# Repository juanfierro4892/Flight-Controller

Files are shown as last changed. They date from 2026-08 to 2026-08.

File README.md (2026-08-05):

Flight Controller 

This is a custom flight controller designed for control rockets.
It uses an STM32F722 microcontroller, ICM-45686 IMU, BMP580 barometer, and has a microSD card for logging flight data. It supports 2S LiPo batteries with onboard charging and has PWM outputs for controlling servos.

The board was designed in KiCad and is fully open source.

PCB: 

3D image: 


Schematic: 


Assembly:

There is no assembly instructions because as it have a lot of components there come assembled from the manufacturer aka JLCPCB

Technical Specifications
Brain: STM32F722RET6 microcontroller.

IMU: ICM-45686 high-precision motion sensor.

Barometer: BMP580 altitude tracker.

Actuation: Multi-channel Servo output via PWM.

Data Logging: Onboard MicroSD card slot.

Power Management:

BQ25883: 2-cell LiPo battery charger via USB-C.

TPS63070: 5V Buck-Boost regulator for servos.

LMR51430: 3.3V Buck regulator for the MCU and sensors..

D2: RGB LED (Common Anode) — Visual status indicator for system boot, ready-to-fly state, and critical errors (IMU, battery, SD card, and power rails).

It is coded in C in visual studio code.

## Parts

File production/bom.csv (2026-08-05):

Designator | Footprint | Quantity | Value | LCSC Part #
C1, C28, C29, C30 | 0402 | 4 | 1uF
C10, C11, C13 | 0805 | 3 | 22uF
C12, C2, C9 | 0603 | 3 | 10uF
C14, C15, C19, C20, C21, C22, C23, C24, C25, C26, C27, C37 | 0201 | 12 | 100nF
C16 | 0603 | 1 | 2.2uF
C17, C18 | 0402 | 2 | 22uF
C3, C31, C5 | 0402 | 3 | 10uF
C32 | 0201 | 1 | 2.2uF
C33, C34 | 0201 | 2 | 20pF
C35, C36 | 0201 | 2 | 6.8pF
C4 | 0201 | 1 | 47nF
C6 | 0603 | 1 | 44uF
C7, C8 | 0805 | 2 | 10uF
CARD1 | TF-SMD_TF-01A | 1 | TF-01A | C91145
D1 | 0402 | 1 | LED
J1 | TerminalBlock_Xinya_XY308-2.54-2P_1x02_P2.54mm_Horizontal | 1 | Screw_Terminal_01x02
J2, J3 | PinHeader_1x03_P2.54mm_Vertical | 2 | Conn_01x03
L4 | L0603 | 1 | FCM1608KF-601T03 | C141723
L5 | L2520 | 1 | DFE252012F-1R0M=P2 | C435392
L6 | IND-SMD_L4.0-W4.0-A | 1 | XFL4020-152MEC | C3033018
L7 | IND-SMD_L3.0-W3.0 | 1 | YHNR3015-5R6M | C18236327
R1, R2 | 0201 | 2 | 5.1K
R10, R11, R12, R13, R16, R17, R18, R19, R20, R21, R22, R6, R7, R8, R9 | 0201 | 15 | 10K
R14 | 0402 | 1 | 100K
R15 | 0402 | 1 | 22.1K
R3 | 0201 | 1 | 383
R4 | 0201 | 1 | 5.23K
R5 | 0201 | 1 | 30.1K
SW1, SW2 | SW-SMD_L3.9-W3.0-P4.45 | 2 | TS-1088-AR02016 | C720477
U1 | VFQFPN-24_L4.0-W4.0-P0.50-BL-EP2.8 | 1 | BQ25883RGER | C544362
U2 | LGA-14_L3.0-W2.5-P0.50-TL | 1 | ICM-45686 | C22459454
U3 | LQFP-64_10x10mm_P0.5mm | 1 | STM32F722RETx
U4 | LGA-10_L2.0-W2.0-P0.50-TL_BMP580 | 1 | BMP580 | C22391138
U5 | VQFN-HR-15_L3.0-W2.5-P0.50-BL_TPS63070RNMR | 1 | TPS63070RNMR | C109322
U6 | SOT-23-6 | 1 | LMR51430
USB1 | USB-C-SMD_TYPE-C-16PIN-2MD-073 | 1 | TYPE-C 16PIN 2MD | C2765186
X1 | CRYSTAL-SMD_4P-L3.2-W2.5-BL | 1 | X322525MOB4SI | C9006
X2 | FC-135R_L3.2-W1.5 | 1 | Q13FC1350000400 | C32346

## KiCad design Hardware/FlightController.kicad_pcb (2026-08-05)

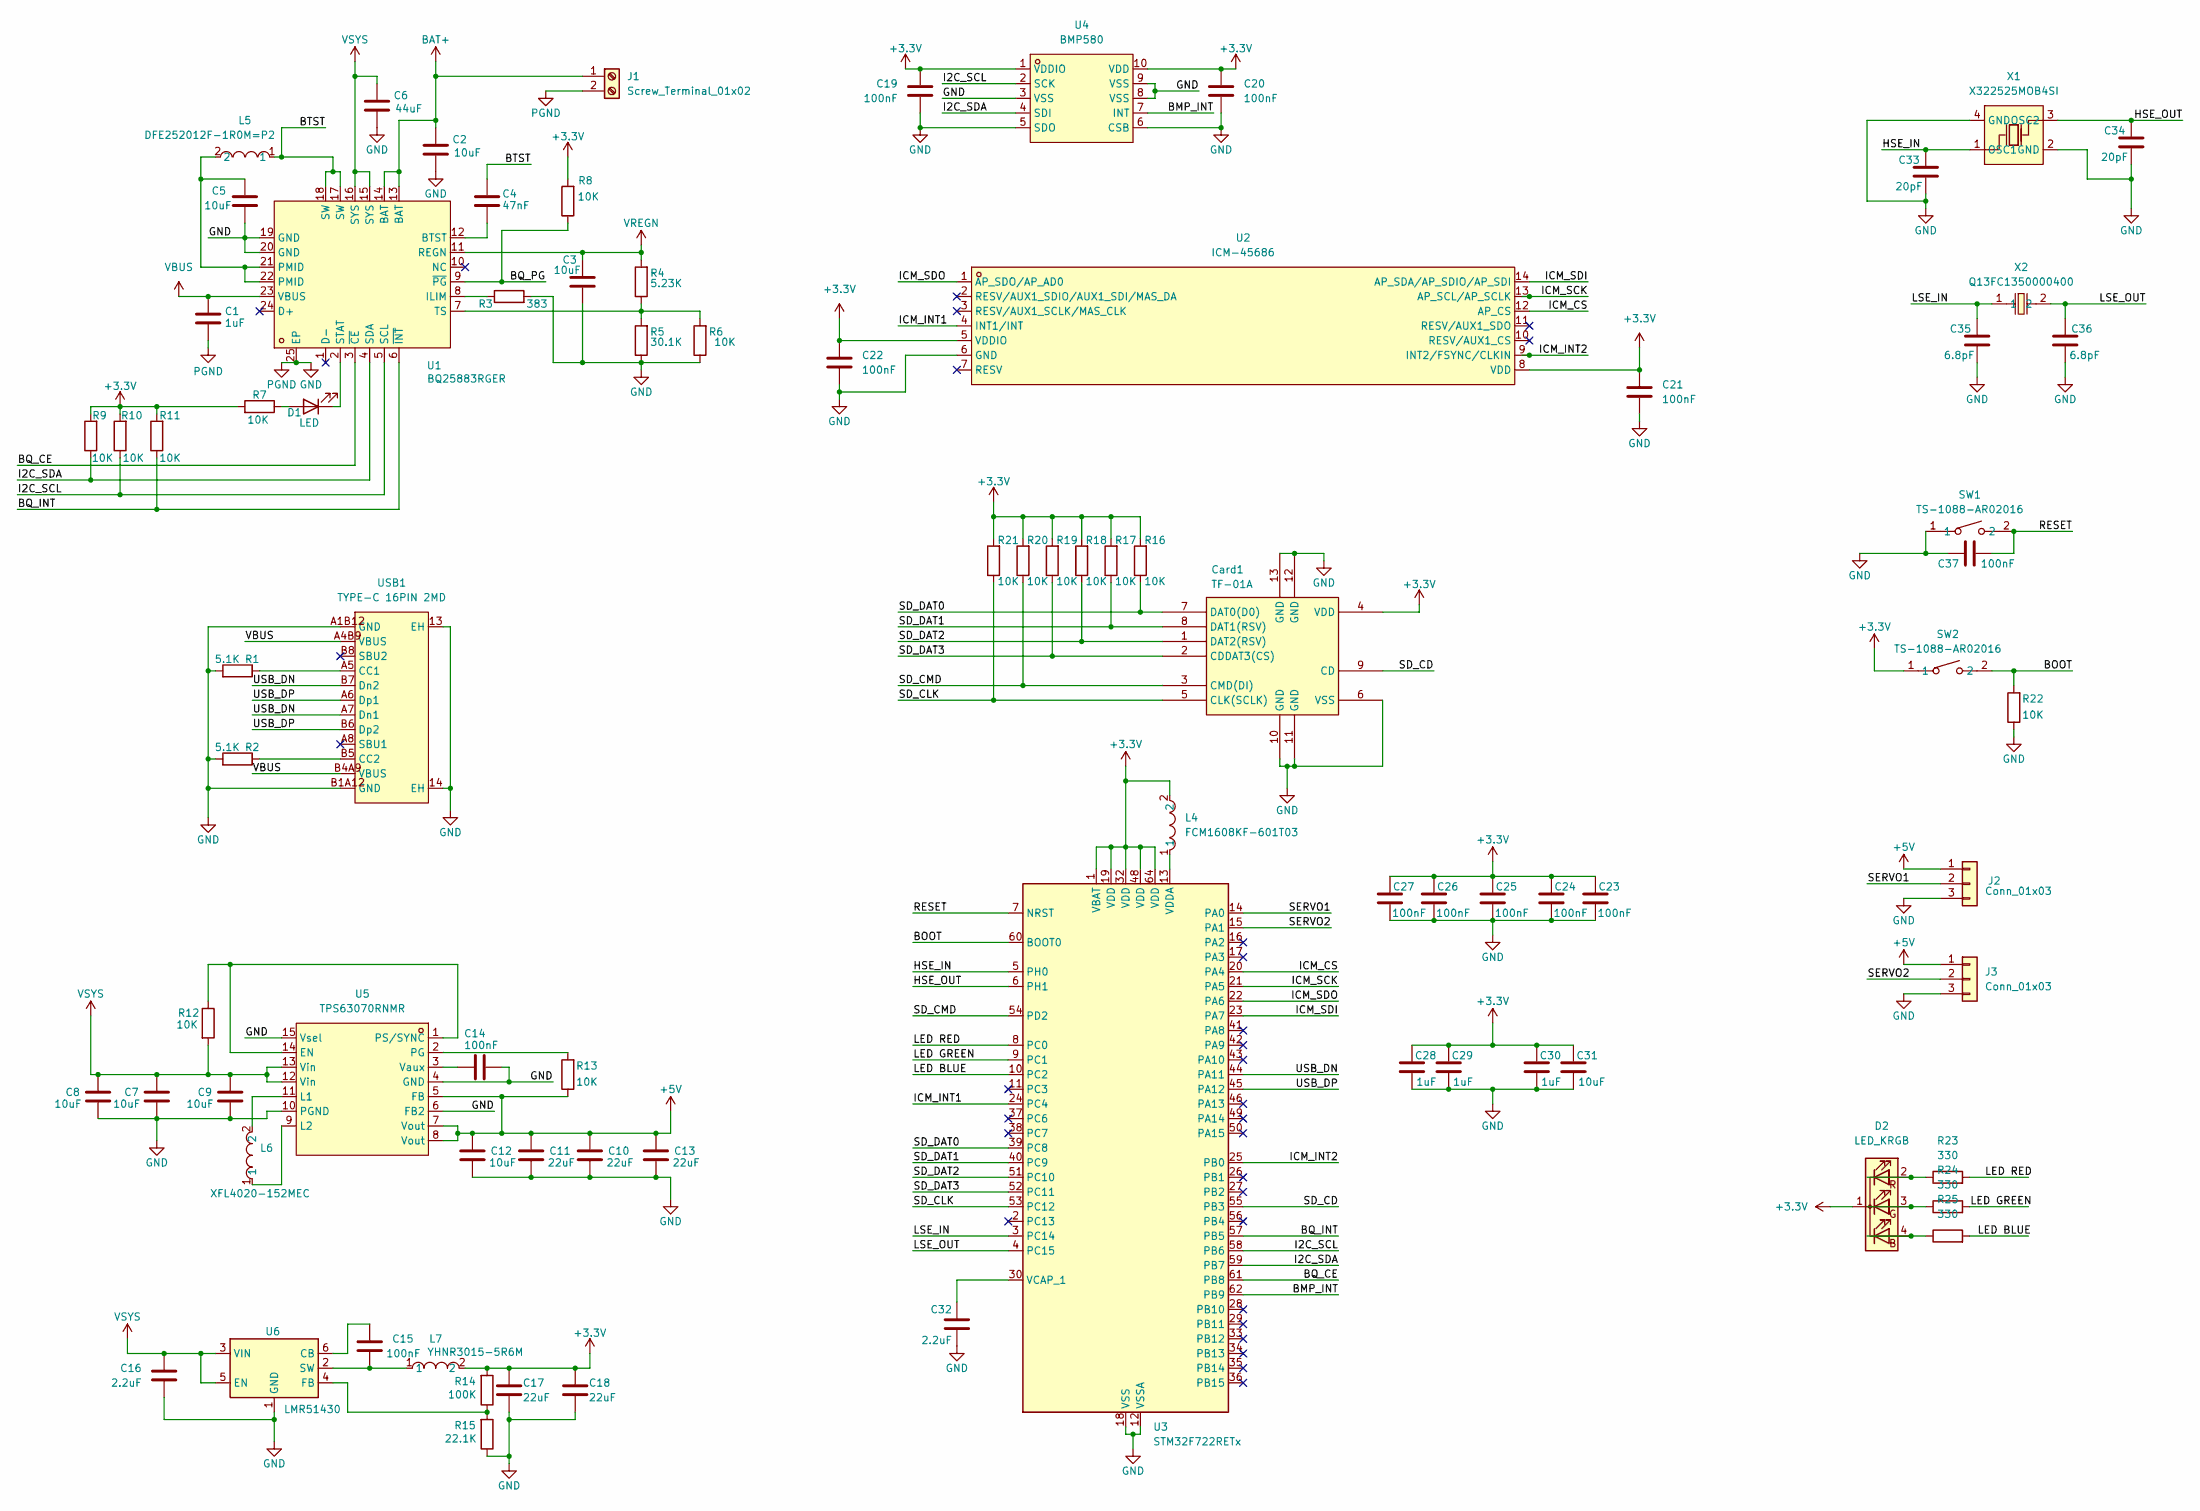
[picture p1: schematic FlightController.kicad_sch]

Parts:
C1, C28, C29, C30: 1uF; C_0402_1005Metric
C2, C9, C12: 10uF; C_0603_1608Metric
C3, C5, C31: 10uF; C_0402_1005Metric
C4: 47nF; C_0201_0603Metric
C6: 44uF; C_0603_1608Metric
C7, C8: 10uF; C_0805_2012Metric
C10, C11, C13: 22uF; C_0805_2012Metric
C14, C15, C19, C20, C21, C22, C23, C24, C25, C26, C27, C37: 100nF; C_0201_0603Metric
C16: 2.2uF; C_0603_1608Metric
C17, C18: 22uF; C_0402_1005Metric
C32: 2.2uF; C_0201_0603Metric
C33, C34: 20pF; C_0201_0603Metric
C35, C36: 6.8pF; C_0201_0603Metric
Card1: TF-01A; TF-SMD_TF-01A; LCSC Part C91145
D1: LED; LED_0402_1005Metric
D2: LED_KRGB; LED_Avago_PLCC4_3.2x2.8mm_CW
J1: Screw_Terminal_01x02; TerminalBlock_Xinya_XY308-2.54-2P_1x02_P2.54mm_Horizontal
J2, J3: Conn_01x03; PinHeader_1x03_P2.54mm_Vertical
L4: FCM1608KF-601T03; L0603; LCSC Part C141723
L5: DFE252012F-1R0M=P2; L2520; LCSC Part C435392
L6: XFL4020-152MEC; IND-SMD_L4.0-W4.0-A; LCSC Part C3033018
L7: YHNR3015-5R6M; IND-SMD_L3.0-W3.0; LCSC Part C18236327
R1, R2: 5.1K; R_0201_0603Metric
R3: 383; R_0201_0603Metric
R4: 5.23K; R_0201_0603Metric
R5: 30.1K; R_0201_0603Metric
R6, R7, R8, R9, R10, R11, R12, R13, R16, R17, R18, R19, R20, R21, R22: 10K; R_0201_0603Metric
R14: 100K; R_0402_1005Metric
R15: 22.1K; R_0402_1005Metric
R23, R24, R25: 330; R_0201_0603Metric
SW1, SW2: TS-1088-AR02016; SW-SMD_L3.9-W3.0-P4.45; LCSC Part C720477
U1: BQ25883RGER; VFQFPN-24_L4.0-W4.0-P0.50-BL-EP2.8; LCSC Part C544362
U2: ICM-45686; LGA-14_L3.0-W2.5-P0.50-TL; LCSC Part C22459454
U3: STM32F722RETx; LQFP-64_10x10mm_P0.5mm
U4: BMP580; LGA-10_L2.0-W2.0-P0.50-TL_BMP580; LCSC Part C22391138
U5: TPS63070RNMR; VQFN-HR-15_L3.0-W2.5-P0.50-BL_TPS63070RNMR; LCSC Part C109322
U6: LMR51430; SOT-23-6
USB1: TYPE-C 16PIN 2MD; USB-C-SMD_TYPE-C-16PIN-2MD-073; MPN TYPE-C 16PIN 2MD(073); LCSC Part C2765186
X1: X322525MOB4SI; CRYSTAL-SMD_4P-L3.2-W2.5-BL; LCSC Part C9006
X2: Q13FC1350000400; FC-135R_L3.2-W1.5; LCSC Part C32346

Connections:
+3.3V: C17.1, C18.1, C19.1, C20.1, C21.1, C22.1, C23.1, C24.1, C25.1, C26.1, C27.1, C28.1, C29.1, C30.1, C31.1, Card1.4 (VDD), D2.1 (K), L4.2, L7.2, R7.2, R8.2, R9.2, R10.2, R11.2, R14.2, R16.2, R17.2, R18.2, R19.2, R20.2, R21.2, SW2.1, U2.5 (VDDIO), U2.8 (VDD), U3.1 (VBAT), U3.19 (VDD), U3.32 (VDD), U3.48 (VDD), U3.64 (VDD), U4.1 (VDDIO), U4.10 (VDD)
+5V: C10.1, C11.1, C12.1, C13.1, J2.1, J3.1, R13.1, U5.5 (FB), U5.7 (Vout), U5.8 (Vout)
/BMP_INT: U3.62 (PB9), U4.7 (INT)
/BOOT: R22.2, SW2.2, U3.60 (BOOT0)
/BQ_CE: U1.3 (~CE), U3.61 (PB8)
/BQ_INT: R11.1, U1.6 (~INT), U3.57 (PB5)
/BQ_PG: R8.1, U1.9 (~PG)
/BTST: C4.1, L5.1, U1.17 (SW), U1.18 (SW)
/HSE_IN: C33.1, U3.5 (PH0), X1.1 (OSC1)
/HSE_OUT: C34.1, U3.6 (PH1), X1.3 (OSC2)
/I2C_SCL: R10.1, U1.5 (SCL), U3.58 (PB6), U4.2 (SCK)
/I2C_SDA: R9.1, U1.4 (SDA), U3.59 (PB7), U4.4 (SDI)
/ICM_CS: U2.12 (AP_CS), U3.20 (PA4)
/ICM_INT1: U2.4 (INT1/INT), U3.24 (PC4)
/ICM_INT2: U2.9 (INT2/FSYNC/CLKIN), U3.25 (PB0)
/ICM_SCK: U2.13 (AP_SCL/AP_SCLK), U3.21 (PA5)
/ICM_SDI: U2.14 (AP_SDA/AP_SDIO/AP_SDI), U3.23 (PA7)
/ICM_SDO: U2.1 (AP_SDO/AP_AD0), U3.22 (PA6)
/LED BLUE: R25.2, U3.10 (PC2)
/LED GREEN: R24.2, U3.9 (PC1)
/LED RED: R23.2, U3.8 (PC0)
/LSE_IN: C35.1, U3.3 (PC14), X2.1
/LSE_OUT: C36.1, U3.4 (PC15), X2.2
/RESET: C37.2, SW1.2, U3.7 (NRST)
/SD_CD: Card1.9 (CD), U3.55 (PB3)
/SD_CLK: Card1.5 (CLK(SCLK)), R21.1, U3.53 (PC12)
/SD_CMD: Card1.3 (CMD(DI)), R20.1, U3.54 (PD2)
/SD_DAT0: Card1.7 (DAT0(D0)), R16.1, U3.39 (PC8)
/SD_DAT1: Card1.8 (DAT1(RSV)), R17.1, U3.40 (PC9)
/SD_DAT2: Card1.1 (DAT2(RSV)), R18.1, U3.51 (PC10)
/SD_DAT3: Card1.2 (CDDAT3(CS)), R19.1, U3.52 (PC11)
/SERVO1: J2.2, U3.14 (PA0)
/SERVO2: J3.2, U3.15 (PA1)
/USB_DN: U3.44 (PA11), USB1.A7 (Dn1), USB1.B7 (Dn2)
/USB_DP: U3.45 (PA12), USB1.A6 (Dp1), USB1.B6 (Dp2)
BAT+: C2.1, J1.1, U1.13 (BAT), U1.14 (BAT)
GND: C1.2, C2.2, C3.2, C5.2, C6.2, C7.2, C8.2, C9.2, C10.2, C11.2, C12.2, C13.2, C14.2, C16.2, C17.2, C18.2, C19.2, C20.2, C21.2, C22.2, C23.2, C24.2, C25.2, C26.2, C27.2, C28.2, C29.2, C30.2, C31.2, C32.2, C33.2, C34.2, C35.2, C36.2, C37.1, Card1.6 (VSS), Card1.10 (GND), Card1.11 (GND), Card1.12 (GND), Card1.13 (GND), J1.2, J2.3, J3.3, R1.2, R2.2, R3.2, R5.1, R6.1, R15.1, R22.1, SW1.1, U1.19 (GND), U1.20 (GND), U1.25 (EP), U2.6 (GND), U3.12 (VSSA), U3.18 (VSS), U3.31 (VSS), U3.47 (VSS), U3.63 (VSS), U4.3 (VSS), U4.5 (SDO), U4.6 (CSB), U4.8 (VSS), U4.9 (VSS), U5.4 (GND), U5.6 (FB2), U5.10 (PGND), U5.15 (Vsel), U6.1 (GND), USB1.13 (EH), USB1.14 (EH), USB1.A1B12 (GND), USB1.B1A12 (GND), X1.2 (GND), X1.4 (GND)
unnamed: C5.1, L5.2, U1.21 (PMID), U1.22 (PMID)
unnamed: D1.2 (A), R7.1
unnamed: D1.1 (K), U1.2 (STAT)
unnamed: D2.4 (BA), R25.1
unnamed: D2.3 (GA), R24.1
unnamed: D2.2 (RA), R23.1
unnamed: C4.2, U1.12 (BTST)
unnamed: R3.1, U1.8 (ILIM)
unnamed: R4.1, R5.2, R6.2, U1.7 (TS)
unnamed: C32.1, U3.30 (VCAP_1)
unnamed: L4.1, U3.13 (VDDA)
unnamed: R12.1, U5.1 (PS/SYNC), U5.14 (EN)
unnamed: L6.2, U5.11 (L1)
unnamed: L6.1, U5.9 (L2)
unnamed: R13.2, U5.2 (PG)
unnamed: C14.1, U5.3 (Vaux)
unnamed: C15.1, U6.6 (CB)
unnamed: R14.1, R15.2, U6.4 (FB)
unnamed: C15.2, L7.1, U6.2 (SW)
unnamed: R1.1, USB1.A5 (CC1)
unnamed: R2.1, USB1.B5 (CC2)
VBUS: C1.1, U1.23 (VBUS), USB1.A4B9 (VBUS), USB1.B4A9 (VBUS)
VREGN: C3.1, R4.2, U1.11 (REGN)
VSYS: C6.1, C7.1, C8.1, C9.1, C16.1, R12.2, U1.15 (SYS), U1.16 (SYS), U5.12 (Vin), U5.13 (Vin), U6.3 (VIN), U6.5 (EN)

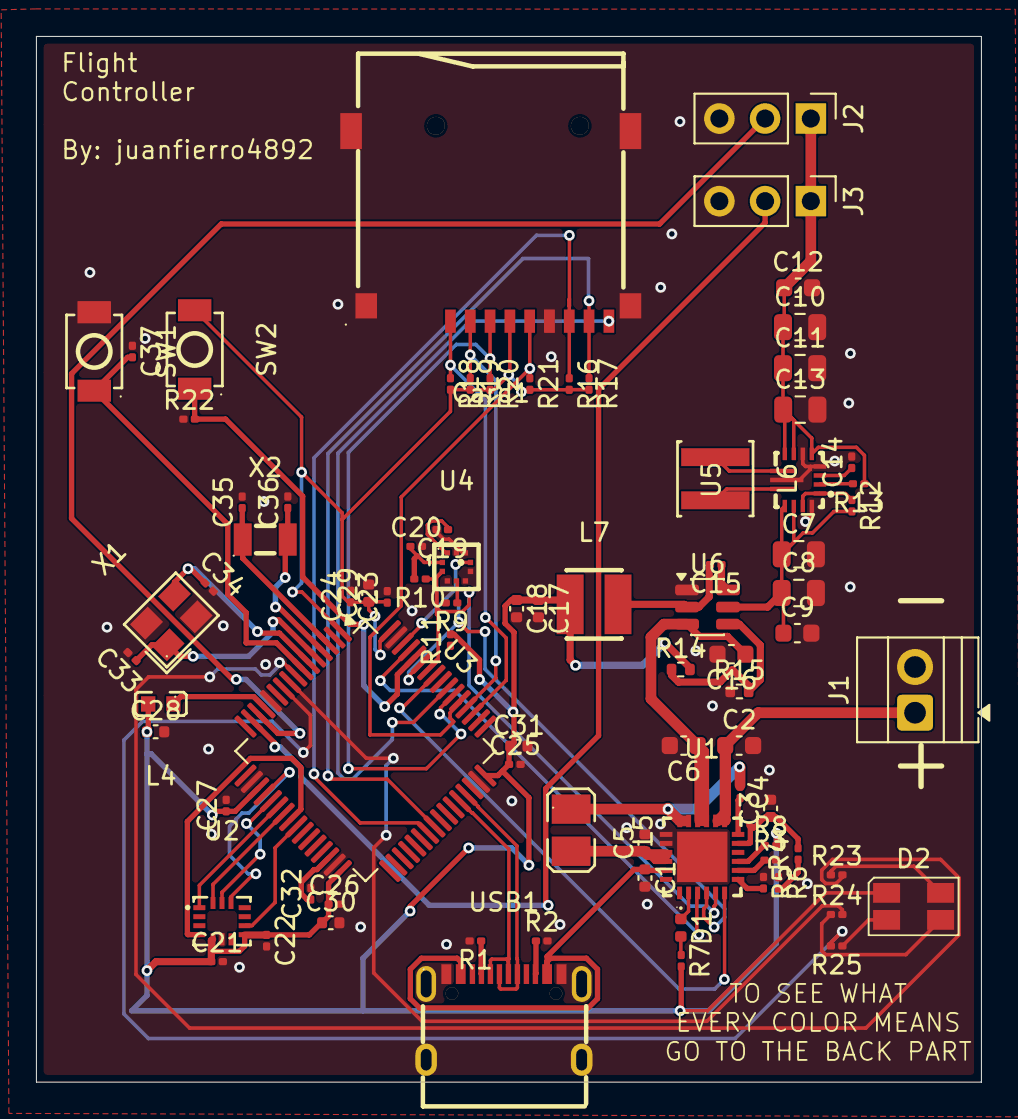
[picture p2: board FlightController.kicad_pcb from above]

Board: 2 copper layers, 52.5 x 58.1 mm, 83 parts (0 on the bottom side), 61 nets.

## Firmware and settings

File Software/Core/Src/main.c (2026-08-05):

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
/* Includes ------------------------------------------------------------------*/
#include "main.h"


I2C_HandleTypeDef hi2c1;

SD_HandleTypeDef hsd1;

SPI_HandleTypeDef hspi1;

TIM_HandleTypeDef htim2;
TIM_HandleTypeDef htim3;

HCD_HandleTypeDef hhcd_USB_OTG_FS;

/* USER CODE BEGIN PV */
static volatile uint8_t led_duty_r = 0;
static volatile uint8_t led_duty_g = 0;
static volatile uint8_t led_duty_b = 0;
static volatile uint16_t pwm_step_counter = 0;
static FC_State_t current_state = FC_STATE_INIT;
static uint32_t cycle_start_tick = 0;
/* USER CODE END PV */

void SystemClock_Config(void);
static void MPU_Config(void);
static void MX_GPIO_Init(void);
static void MX_I2C1_Init(void);
static void MX_SDMMC1_SD_Init(void);
static void MX_SPI1_Init(void);
static void MX_USB_OTG_FS_HCD_Init(void);
static void MX_TIM2_Init(void);
static void MX_TIM3_Init(void);
/* USER CODE BEGIN 0 */
typedef struct
{
  uint8_t r, g, b;
  uint16_t blink_ms;
  uint8_t blink_count;
  uint8_t continuous;
} LedPattern_t;

static const LedPattern_t led_patterns[] =
{
  [FC_STATE_INIT]        = {  0,   0, 100,  500, 1, 1 },
  [FC_STATE_READY]       = {  0, 100,   0,    0, 0, 0 },
  [FC_STATE_ERROR_IMU]   = {100,   0,   0,  120, 1, 1 },
  [FC_STATE_LOW_BATTERY] = {100,  90,   0,  500, 1, 1 },
  [FC_STATE_ERROR_SD]    = { 70,   0, 100, 1500, 2, 0 },
  [FC_STATE_ERROR_POWER] = {  0, 100, 100,    0, 0, 0 },
};

static void LED_Status_SetColorRGB(uint8_t r, uint8_t g, uint8_t b)
{
  led_duty_r = (r > 100U) ? 100U : r;
  led_duty_g = (g > 100U) ? 100U : g;
  led_duty_b = (b > 100U) ? 100U : b;
}

void LED_Status_Init(void)
{
  uint32_t timer_clk;

  led_duty_r = 0;
  led_duty_g = 0;
  led_duty_b = 0;
  pwm_step_counter = 0;
  cycle_start_tick = HAL_GetTick();

  timer_clk = HAL_RCC_GetPCLK1Freq();
  if ((RCC->CFGR & RCC_CFGR_PPRE1) != RCC_CFGR_PPRE1_DIV1)
  {
    timer_clk *= 2U;
  }
  __HAL_TIM_SET_AUTORELOAD(&htim3, (timer_clk / LED_PWM_TICK_HZ) - 1U);
  __HAL_TIM_SET_COUNTER(&htim3, 0);

  HAL_TIM_Base_Start_IT(&htim3);
}

void LED_Status_Set(FC_State_t state)
{
  if (state != current_state)
  {
    current_state = state;
    cycle_start_tick = HAL_GetTick();
  }
}

void LED_Status_Update(void)
{
  const LedPattern_t *p = &led_patterns[current_state];
  uint32_t elapsed;

  if (current_state == FC_STATE_ERROR_POWER)
  {
    static const uint16_t erratic_ms[] = { 60, 180, 40, 260, 90, 400 };
    const uint8_t n = sizeof(erratic_ms) / sizeof(erratic_ms[0]);
    uint32_t t = HAL_GetTick() % 1030U;
    uint32_t acc = 0;
    uint8_t i;

    for (i = 0; i < n; i++)
    {
      acc += erratic_ms[i];
      if (t < acc)
      {
        break;
      }
    }
    if ((i % 2U) == 0U)
    {
      LED_Status_SetColorRGB(p->r, p->g, p->b);
    }
    else
    {
      LED_Status_SetColorRGB(0, 0, 0);
    }
    return;
  }

  if (p->blink_ms == 0U)
  {
    LED_Status_SetColorRGB(p->r, p->g, p->b);
    return;
  }

  elapsed = HAL_GetTick() - cycle_start_tick;
  if (elapsed >= p->blink_ms)
  {
    cycle_start_tick = HAL_GetTick();
    elapsed = 0;
  }

  if (p->continuous)
  {
    uint8_t on = (elapsed < (p->blink_ms / 2U));
    LED_Status_SetColorRGB(on ? p->r : 0, on ? p->g : 0, on ? p->b : 0);
    return;
  }

  {
    uint16_t slot = p->blink_ms / (uint16_t)(p->blink_count * 2U + 2U);
    uint16_t phase = (uint16_t)(elapsed / slot);

    if ((phase < (uint16_t)(p->blink_count * 2U)) && ((phase % 2U) == 0U))
    {
      LED_Status_SetColorRGB(p->r, p->g, p->b);
    }
    else
    {
      LED_Status_SetColorRGB(0, 0, 0);
    }
  }
}

static void LED_Status_PWM_Tick(void)
{
  pwm_step_counter++;
  if (pwm_step_counter >= LED_PWM_STEPS)
  {
    pwm_step_counter = 0;
  }
  HAL_GPIO_WritePin(LED_R_GPIO_Port, LED_R_Pin,
                     (pwm_step_counter < led_duty_r) ? GPIO_PIN_SET : GPIO_PIN_RESET);
  HAL_GPIO_WritePin(LED_G_GPIO_Port, LED_G_Pin,
                     (pwm_step_counter < led_duty_g) ? GPIO_PIN_SET : GPIO_PIN_RESET);
  HAL_GPIO_WritePin(LED_B_GPIO_Port, LED_B_Pin,
                     (pwm_step_counter < led_duty_b) ? GPIO_PIN_SET : GPIO_PIN_RESET);
}

void HAL_TIM_PeriodElapsedCallback(TIM_HandleTypeDef *htim)
{
  if (htim->Instance == TIM3)
  {
    LED_Status_PWM_Tick();
  }
}
/* USER CODE END 0 */

/**
  * @brief  The application entry point.
  * @retval int
  */
int main(void)
{

  /* USER CODE BEGIN 1 */
extern TIM_HandleTypeDef htim3;

void TIM3_IRQHandler(void)
{
  HAL_TIM_IRQHandler(&htim3);
}
  /* USER CODE END 1 */

  /* MPU Configuration--------------------------------------------------------*/
  MPU_Config();

  /* MCU Configuration--------------------------------------------------------*/

  /* Reset of all peripherals, Initializes the Flash interface and the Systick. */
  HAL_Init();

  /* Configure the system clock */
  SystemClock_Config();

  /* Initialize all configured peripherals */
  MX_GPIO_Init();
  MX_I2C1_Init();
  MX_SDMMC1_SD_Init();
  MX_SPI1_Init();
  MX_USB_OTG_FS_HCD_Init();
  MX_TIM2_Init();
  MX_TIM3_Init();
  /* USER CODE BEGIN 2 */
  LED_Status_Init();
  LED_Status_Set(FC_STATE_INIT);
  /* USER CODE END 2 */

  /* Infinite loop */
  /* USER CODE BEGIN WHILE */
  while (1)
  {
    /* USER CODE END WHILE */
 LED_Status_Update();
    /* USER CODE BEGIN 3 */
  }
  /* USER CODE END 3 */
}

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
 /* MPU Configuration */

void MPU_Config(void)
{
  MPU_Region_InitTypeDef MPU_InitStruct = {0};

  /* Disables the MPU */
  HAL_MPU_Disable();

  /** Initializes and configures the Region and the memory to be protected
  */
  MPU_InitStruct.Enable = MPU_REGION_ENABLE;
  MPU_InitStruct.Number = MPU_REGION_NUMBER0;
  MPU_InitStruct.BaseAddress = 0x0;
  MPU_InitStruct.Size = MPU_REGION_SIZE_4GB;
  MPU_InitStruct.SubRegionDisable = 0x87;
  MPU_InitStruct.TypeExtField = MPU_TEX_LEVEL0;
  MPU_InitStruct.AccessPermission = MPU_REGION_NO_ACCESS;
  MPU_InitStruct.DisableExec = MPU_INSTRUCTION_ACCESS_DISABLE;
  MPU_InitStruct.IsShareable = MPU_ACCESS_SHAREABLE;
  MPU_InitStruct.IsCacheable = MPU_ACCESS_NOT_CACHEABLE;
  MPU_InitStruct.IsBufferable = MPU_ACCESS_NOT_BUFFERABLE;

  HAL_MPU_ConfigRegion(&MPU_InitStruct);
  /* Enables the MPU */
  HAL_MPU_Enable(MPU_PRIVILEGED_DEFAULT);

}

/**
  * @brief  This function is executed in case of error occurrence.
  * @retval None
  */
void Error_Handler(void)
{
  /* USER CODE BEGIN Error_Handler_Debug */
  /* User can add his own implementation to report the HAL error return state */
  __disable_irq();
  while (1)
  {
  }
  /* USER CODE END Error_Handler_Debug */
}
#ifdef USE_FULL_ASSERT
/**
  * @brief  Reports the name of the source file and the source line number
  *         where the assert_param error has occurred.
  * @param  file: pointer to the source file name
  * @param  line: assert_param error line source number
  * @retval None
  */
void assert_failed(uint8_t *file, uint32_t line)
{
  /* USER CODE BEGIN 6 */
  /* User can add his own implementation to report the file name and line number,
     ex: printf("Wrong parameters value: file %s on line %d\r\n", file, line) */
  /* USER CODE END 6 */
}
#endif /* USE_FULL_ASSERT */

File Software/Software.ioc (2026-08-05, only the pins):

Mcu.UserName=STM32F722RETx
PA0-WKUP.Signal=S_TIM2_CH1_ETR
PA1.Signal=S_TIM2_CH2
PA11.Signal=USB_OTG_FS_DM
PA12.Signal=USB_OTG_FS_DP
PA4.Signal=SPI1_NSS
PA5.Signal=SPI1_SCK
PA6.Signal=SPI1_MISO
PA7.Signal=SPI1_MOSI
PB3.GPIO_Label=SD_CS
PB3.Signal=GPIO_Input
PB5.GPIO_Label=BQ_INT
PB5.Signal=GPXTI5
PB6.Signal=I2C1_SCL
PB7.Signal=I2C1_SDA
PB8.GPIO_Label=BQ_CE
PB8.Signal=GPIO_Output
PB9.GPIO_Label=BMP_INT
PB9.Signal=GPXTI9
PC0.GPIO_Label=LED R
PC0.Signal=GPIO_Output
PC1.GPIO_Label=LED G
PC1.Signal=GPIO_Output
PC10.Signal=SDMMC1_D2
PC11.Signal=SDMMC1_D3
PC12.Signal=SDMMC1_CK
PC14-OSC32_IN.Signal=RCC_OSC32_IN
PC15-OSC32_OUT.Signal=RCC_OSC32_OUT
PC2.GPIO_Label=LED B
PC2.Signal=GPIO_Output
PC4.GPIO_Label=ICM_INT1
PC4.Signal=GPXTI4
PC8.Signal=SDMMC1_D0
PC9.Signal=SDMMC1_D1
PD2.Signal=SDMMC1_CMD
PH0-OSC_IN.Signal=RCC_OSC_IN
PH1-OSC_OUT.Signal=RCC_OSC_OUT

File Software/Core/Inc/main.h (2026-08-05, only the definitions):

#define LED_R_Pin GPIO_PIN_0
#define LED_R_GPIO_Port GPIOC
#define LED_G_Pin GPIO_PIN_1
#define LED_G_GPIO_Port GPIOC
#define LED_B_Pin GPIO_PIN_2
#define LED_B_GPIO_Port GPIOC
#define ICM_INT1_Pin GPIO_PIN_4
#define ICM_INT1_GPIO_Port GPIOC
#define SD_CS_Pin GPIO_PIN_3
#define SD_CS_GPIO_Port GPIOB
#define BQ_INT_Pin GPIO_PIN_5
#define BQ_INT_GPIO_Port GPIOB
#define BQ_CE_Pin GPIO_PIN_8
#define BQ_CE_GPIO_Port GPIOB
#define BMP_INT_Pin GPIO_PIN_9
#define BMP_INT_GPIO_Port GPIOB
#define LED_PWM_STEPS      100U
#define LED_PWM_REFRESH_HZ 200U
#define LED_PWM_TICK_HZ    (LED_PWM_STEPS * LED_PWM_REFRESH_HZ)

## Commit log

2026-08-05 Uploading all the files of the controller to the REPO
    [FlightController.kicad_pcb, FlightController.kicad_sch, bom.csv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]
2026-08-05 Add README for custom flight controller project
    Added detailed information about the flight controller, including specifications, assembly notes, and images.

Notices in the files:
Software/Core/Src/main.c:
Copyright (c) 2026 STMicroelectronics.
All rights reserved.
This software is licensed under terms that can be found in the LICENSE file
